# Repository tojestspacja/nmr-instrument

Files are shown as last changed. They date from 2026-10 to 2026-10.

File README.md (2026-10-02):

# Benchtop NMR instrument (TIGP 2026, Project 3)

Yi-Tsai Liang (`tojestspacja`). This repository is the canonical home of my Project 3: a 2 mT
benchtop NMR instrument built around the course's class board.

**Project site:** <https://tojestspacja.github.io/nmr-instrument/> ·
**Interactive simulator:** <https://tojestspacja.github.io/nmr-instrument/simulator/>

> **Status: design stage.** Designed and cross-checked in OpenSCAD; nothing printed, cut or measured
> yet. Every spectrum and signal here is simulated; there are no physical measurements so far.

## What lives where

| Content | Home |
| --- | --- |
| Project narrative, CAD, fabrication files, renders, simulator, analysis | **this repository** |
| The real PCBs, ESP32 firmware, NMR pulse sequence, the instrument's own web UI | [class-board-2026](https://github.com/TIGP-Experimental-Methods/class-board-2026), pinned in [`hardware/README.md`](hardware/README.md) |
| How the course finds this project | one card on the [class showcase](https://tigp-experimental-methods.github.io/showcase-2026/), linking to the site |

The rule: changing my Project 3 → work here. Changing the real PCB, firmware, pulse sequence or
instrument UI → work in class-board-2026. Changing how the course finds the project → edit only the
showcase card.

Three interfaces, three jobs:

```text
Course showcase card           "What is this project?"            -> links to the site
This site + /simulator/         "How is it built, how does it work?" -> simulation and explanation only
instrument-XXXX.local           "Operate the real instrument"        -> served by the ESP32 on local Wi-Fi
```

The simulator does not control the board, and cannot: it is a public HTTPS page, and the instrument
is a local-network device. Real scans start at `instrument-XXXX.local` → NMR → Apply settings → Start.

## Layout

| Path | What |
| --- | --- |
| `index.html` | the project site's landing page (GitHub Pages serves this repository's root, `main`) |
| `simulator/` | NMR Bench Setup: 3D bench and Bloch-equation pulse simulator (`simulator/README.md`) |
| `mechanical/` | the OpenSCAD project: housing, probe, B0 pair, bench checks, data model, simulator `spectrum.py` (`mechanical/README.md`) |
| `fabrication/` | laser and water-jet exports and `CUT-LIST.md`, generated by `mechanical/export_cut.py` |
| `hardware/README.md` | the class-board-2026 dependency: reference commit and the exact files |
| `tools/handin.py` | writes the course hand-in copy of the housing into class-board-2026 |

The CAD previews read the board meshes from class-board-2026 cloned beside this repository
(`../class-board-2026`); see `hardware/README.md`.

## History

The simulator started here; the OpenSCAD project started in class-board-2026
(`docs/students/yi-tsai/housing/`) and was brought in with `git subtree`, so its history is in this
repository too. That folder now holds only the course hand-in, generated by `tools/handin.py`.

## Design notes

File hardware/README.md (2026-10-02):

# Hardware and firmware

The instrument's electronics, firmware and on-board user interface are **not** in this repository.
They are developed in the shared course repository `class-board-2026`, which the instructor and other
students also change, and that repository is the source of truth for them. Nothing here copies them:
no firmware, no PCB project, no second version of the pulse sequence.

## Project 3 reference version

| | |
| --- | --- |
| Repository | [TIGP-Experimental-Methods/class-board-2026](https://github.com/TIGP-Experimental-Methods/class-board-2026) |
| Branch | `main` |
| Commit | [`eef00d20a10deca994a8efe07c588c22af2b9db0`](https://github.com/TIGP-Experimental-Methods/class-board-2026/tree/eef00d20a10deca994a8efe07c588c22af2b9db0) |
| Date | 2026-10-02 |

Everything in this repository was designed and checked against that commit: the housing against its
board meshes, and the simulator and documentation against its firmware. My working branch
`w1-yi-tsai` contains this commit and differs from it only under `docs/students/`.

| What | Path in class-board-2026 (links are pinned to the reference commit) |
| --- | --- |
| Main PCB | [`hardware/class-board.kicad_pro`](https://github.com/TIGP-Experimental-Methods/class-board-2026/blob/eef00d20a10deca994a8efe07c588c22af2b9db0/hardware/class-board.kicad_pro) |
| Front-panel PCB | [`hardware/front-panel/front-panel.kicad_pro`](https://github.com/TIGP-Experimental-Methods/class-board-2026/blob/eef00d20a10deca994a8efe07c588c22af2b9db0/hardware/front-panel/front-panel.kicad_pro) |
| Board meshes the housing is built round | [`hardware/release/`](https://github.com/TIGP-Experimental-Methods/class-board-2026/tree/eef00d20a10deca994a8efe07c588c22af2b9db0/hardware/release) (`class-board.stl`, `front-panel.stl`, `.step`) |
| NMR pulse sequencer | [`firmware/src/blocks/nmr/Sequencer.cpp`](https://github.com/TIGP-Experimental-Methods/class-board-2026/blob/eef00d20a10deca994a8efe07c588c22af2b9db0/firmware/src/blocks/nmr/Sequencer.cpp), one scan in [`runOneScan()`, lines 386–500](https://github.com/TIGP-Experimental-Methods/class-board-2026/blob/eef00d20a10deca994a8efe07c588c22af2b9db0/firmware/src/blocks/nmr/Sequencer.cpp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) |
| NMR firmware contract and default settings | [`firmware/NMR-FIRMWARE.md`](https://github.com/TIGP-Experimental-Methods/class-board-2026/blob/eef00d20a10deca994a8efe07c588c22af2b9db0/firmware/NMR-FIRMWARE.md) |
| Commands and record format | [`firmware/PROTOCOL.md`](https://github.com/TIGP-Experimental-Methods/class-board-2026/blob/eef00d20a10deca994a8efe07c588c22af2b9db0/firmware/PROTOCOL.md) |
| NMR instrument web UI (served by the ESP32) | [`host/pwa/panels/nmr.js`](https://github.com/TIGP-Experimental-Methods/class-board-2026/blob/eef00d20a10deca994a8efe07c588c22af2b9db0/host/pwa/panels/nmr.js) |
| Command-line client (`instrument nmr --csv`) | [`host/instrument.py`](https://github.com/TIGP-Experimental-Methods/class-board-2026/blob/eef00d20a10deca994a8efe07c588c22af2b9db0/host/instrument.py) |

## How a real scan runs

The pulse program runs on the ESP32. `runOneScan()` in `Sequencer.cpp` does this for each scan:

1. optional pre-polarization (`polarize_ms`, then `t_polarize_settle_ms`);
2. sets this scan's pulse phase;
3. blanks the receiver, then holds `TX_EN` high for the 90° pulse (`t90_us`); in echo mode it waits
   `tau_us` and gives the 180° pulse;
4. waits out the dead time (`t_dead_us`), while the coil is still ringing, then releases `RX_BLANK`;
5. starts the ADC burst at `t_acq_start_us` after the pulse and records for `t_acq_ms`.

The scan set repeats this `n_avg` times, `t_repeat_ms` apart, and cycles the pulse phase between
scans (CYCLOPS) when `cyclops` is on. The default values of these settings are in `NMR-FIRMWARE.md` at
the reference commit; they are deliberately not copied here, so they cannot go stale.

Note that class-board-2026's own guidance (`CLAUDE.md`, "Real-hardware code is unverified until
measured") treats the real-hardware branch of this code as a hypothesis until `hardware/docs/bring-up.md`
says otherwise; only its SIM mode has run.

## Three interfaces, three jobs

```text
Course showcase card ──────────► "What is this project?"   (one card, links here)

Public browser (GitHub Pages)
   └─► this site + /simulator/  ──► "How is it built, how does it work?"   simulation only

Phone or laptop on the local Wi-Fi
   └─► instrument-XXXX.local    ──► "Operate the real instrument"
          └─► ESP32 ─► TX / RX / ADC hardware
```

The public site cannot drive the board: it is served over HTTPS from the internet, and the
instrument is a plain `ws://` device on your local network. Real scans are started from
`instrument-XXXX.local` → **NMR** → **Apply settings** → **Start** (or **Pulse** for a single test
pulse), or from a laptop with `instrument nmr --n-avg 8 --csv fid.csv`.

## Building this repository's CAD against the boards

The OpenSCAD files in `../mechanical/` read the board meshes from a sibling checkout:

```text
tigp-2026/
├── class-board-2026/      (at the reference commit, or a later one)
└── nmr-instrument/        (this repository)
```

Only previews use them (`boards.scad`, the housing's assembly view, the simulator's mesh build);
none of the exported parts depends on them. If the boards change in `class-board-2026`, re-check the
housing against the new meshes and update the reference commit above.

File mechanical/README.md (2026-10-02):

# mechanical/: the OpenSCAD project

The housing, the probe, the B0 coil pair, the whole bench and the printable data model, as one
OpenSCAD project with one set of shared numbers. The story of how it was designed is on the project
site: <https://tojestspacja.github.io/nmr-instrument/>.

The files stay together in one folder because they include each other (`include <nmr-params.scad>`,
`use <housing.scad>`, `cut-*.scad` on the 3D files); splitting them would mean rewriting those links.
The flat-part exports go to `../fabrication/`.

| File | What it is |
| --- | --- |
| `nmr-params.scad` | the shared numbers: firmware defaults, the coil, water, copper. Change them here and nowhere else |
| `housing.scad` → `base-shell.stl`, `hood.stl`, `coupon.stl`, `bottom-plate.dxf`, `housing.png` | the printed housing; `part` = `shell`, `hood`, `coupon`, `plate` |
| `probe.scad` → `probe-former.stl`, `probe-sleeve.stl`, `probe-cradle.stl`, `probe.png`, `probe-b0.png` | coil former, 50 mL sample sleeve, tripod cradle; the B0 pair as a reference design |
| `instrument.scad` → `instrument.png` | the whole bench and its cross-checks: cables, RX tank, B0 drive and drift, steel near the sample, TX/RX |
| `boards.scad` | the two boards stacked, from the housing's own numbers |
| `spectrum.py` → `spectrum-data.scad` | the probe simulator (field over the sample, dead time, tank, coil heating), or real records from `instrument nmr --csv` |
| `spectrum.scad` → `spectrum.stl`, `spectrum.png` | the printable data model (simulated data) |
| `cut-common.scad`, `cut-housing.scad`, `cut-probe.scad`, `cut-spectrum.scad`, `export_cut.py` | every part flat for the laser and the water-jet; `py export_cut.py` writes `../fabrication/` |
| `img/` | renders for the project site |

## The board meshes

The housing is built round the boards' meshes, which belong to class-board-2026
(`hardware/release/`) and are not copied here. `housing.scad`'s `board_dir` reads them from a checkout
of class-board-2026 beside this repository; the reference commit is in `../hardware/README.md`. Only
previews need them; no exported part does.

## The course hand-in

The course collects the housing from class-board-2026 (`docs/students/yi-tsai/housing/`). That copy is
generated from this folder by `py ../tools/handin.py`; edit here, never there.

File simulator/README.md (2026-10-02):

# NMR bench simulator (Project 3: `simulator/`)

Part of the Project 3 site: <https://tojestspacja.github.io/nmr-instrument/simulator/>. **Simulation only:** it does not
control the instrument; the real pulse sequence is `runOneScan()` in class-board-2026
`firmware/src/blocks/nmr/Sequencer.cpp` (reference commit in `../hardware/README.md`).

A live 3D view of the whole setup — probe on its tripod inside the B0 Helmholtz pair, cabled to the
housing — with a pulse experiment that solves the Bloch equations for the real design. Open
`index.html` through a web server (it loads the meshes with `fetch`, which a `file://` page cannot):

```sh
py -m http.server 8000      # in this folder, then open http://localhost:8000/
```

## What the pulse experiment computes

- **Fields, exact (default):** precomputed in Mathematica by `build/nmr_exact.wls` and stored in
  `m/fieldmap-tube.json` / `m/fieldmap-bottle.json` (one entry per voxel on a 2.5 mm / 3 mm grid):
  Biot–Savart for the B0 pair with its real 28 × 27 mm winding cross-section (5 × 5 filaments per
  coil) and for every one of the class coil's 400 turns (222 in the first layer, 178 in the second),
  giving each voxel its line offset and the strength and direction of B1 perpendicular to the local B0.
  The page scales B0 with the current and adds the Earth's field along B0. **Approximate** (switch on
  the page, and the fallback if the maps do not load): 4th-order Helmholtz error and the on-axis
  finite-solenoid profile.
- **Pulse:** the class coil driven at 7.95 V pk (5.6 mA at 89.4 kHz); rotating component = half the
  linear field; an exact rotation per voxel about its effective field in the frame rotating at f_tx,
  off-resonance and the B1 direction included.
- **FID:** free precession at each voxel's own offset, intrinsic T2 = 2 s, T1 recovery 2.5 s.
- **Receiver:** reciprocity pickup with the same coil field (and phase), the Q = 10 tank tuned to
  88.47 kHz (C710 only + the coax, `instrument.scad`), mixing to the 5.4 kHz IF, 1.2 ms blanking,
  tank + OPA1656 noise 15.6 nV/√Hz over 15 kHz, ADC gain 1.02 V / 40 µV, 25 kS/s.

### Checked against SpinDynamica

`build/nmr_exact.wls` also runs the pulse on every voxel with SpinDynamica 3.7.1 (C. Bengs and
M. H. Levitt, *Magn. Reson. Chem.* 2017, doi:10.1002/mrc.4642) and computes the FID and spectrum
independently. Same voxels, f_tx 89.4 kHz, 417 µs, 1.5 A, no Earth field:

| | tube: `physics.js` | tube: SpinDynamica | bottle: `physics.js` | bottle: SpinDynamica |
|---|---|---|---|---|
| coil emf, µV pk | 0.902 | 0.902 | 1.643 | 1.643 |
| proton line, Hz | 89 559 | 89 560 | 89 559 | 89 560 |
| linewidth FWHM, Hz | 6 | 6 | 6 | 6 |
| T2* (envelope to 1/e), ms | 79.9 | 80.5 | 41.0 | 41.5 |
| 90° at the coil centre, µs | 417.4 | 417.4 | 417.4 | 417.4 |

What it shows about the design: at 1.5 A the pair gives **2.1035 mT**, not the thin-wire formula's
2.0997 mT, so the line sits at **89 560 Hz**, 160 Hz above the default f_tx (retune, or 1.497 A);
the 90° pulse at the coil centre is **417 µs** as the workbook says (the second layer is only 178
turns long, which the approximate model's even winding misses and puts at 451 µs); the 50 mL tube
gives **0.90 µV** at the coil, **8.8 µV** at the tank, a fifth of the 40 µV the receiver was sized
for (single-sample SNR about 4; the bottle 15.9 µV); T2* is **80 ms** in the tube, **42 ms** in the
bottle (it reaches the coil ends), line 6 Hz; the Earth's field along B0 moves the line 42.6 Hz per µT.

### Recomputing the field maps

Needs Mathematica (13.3 used) and SpinDynamica 3.7.x (free, <https://www.spindynamica.soton.ac.uk/downloads/>;
the newest release needs Mathematica 14.3). Point `SPINDYNAMICA` at its folder (the one holding
`SpinDynamica/`), then:

```sh
cd build
wolframscript -file nmr_exact.wls 2.5 Infinity tube      # about 5 min; writes exact-tube-*.json/.png
wolframscript -file nmr_exact.wls 3 Infinity bottle      # about 5 min
py compact.py tube ../m/fieldmap-tube.json
py compact.py bottle ../m/fieldmap-bottle.json
```

## Files

| File | What it is |
|---|---|
| `index.html` | the page (three.js r147 and pako from CDNs) |
| `physics.js` | the simulation, pure functions; `build/test-physics.js` runs it in Node |
| `m/*.txt` | the meshes: gzip(float32 positions + uint32 indices), base64 |
| `m/fieldmap-*.json` | the exact field maps, with the SpinDynamica results they were checked against |
| `build/nmr_exact.wls`, `build/compact.py` | the Mathematica / SpinDynamica computation and its packer |
| `build/exp-probe.scad`, `build/exp-housing.scad` | one component per run, in `instrument.scad`'s frame |
| `build/pack.py` | ASCII STL → the `m/*.txt` files |

## Rebuilding the meshes after a design change

```sh
cd build      # sources: ../../mechanical/*.scad; board meshes: ../../../class-board-2026/hardware/release/
# one STL per component (OpenSCAD on PATH); the list is in index.html, PARTS
openscad -o meshes/cradle.stl -D 'comp="cradle"' exp-probe.scad      # ... and so on
openscad -o meshes/box.stl    -D 'comp="box"'    exp-housing.scad
py pack.py                  # writes ../m/*.txt
node test-physics.js        # the physics numbers
```

The checks list in `index.html` quotes `instrument.scad`'s echoes; update it when they change.

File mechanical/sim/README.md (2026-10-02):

# NMR bench simulator

A live 3D view of the whole setup — probe on its tripod inside the B0 Helmholtz pair, cabled to the
housing — with a pulse experiment that solves the Bloch equations for the real design. Open
`index.html` through a web server (it loads the meshes with `fetch`, which a `file://` page cannot):

```sh
py -m http.server 8000      # in this folder, then open http://localhost:8000/
```

## What the pulse experiment computes

- **Field:** 3000 voxels of the sample in the B0 pair's field (Helmholtz, 4th-order error term) plus
  the Earth's field along B0.
- **Pulse:** the class coil driven at 7.95 V pk (5.6 mA at 89.4 kHz); B1 from the finite-solenoid
  on-axis profile, rotating component = half the linear field; an exact rotation per voxel about
  its effective field in the frame rotating at f_tx, off-resonance included.
- **FID:** free precession at each voxel's own offset, intrinsic T2 = 2 s, T1 recovery 2.5 s.
- **Receiver:** reciprocity pickup with the same coil profile, the Q = 10 tank tuned to 88.47 kHz
  (C710 only + the coax, `instrument.scad`), mixing to the 5.4 kHz IF, 1.2 ms blanking, tank +
  OPA1656 noise 15.6 nV/√Hz over 15 kHz, ADC gain 1.02 V / 40 µV, 25 kS/s.

What it shows about the design: the 90° pulse at the coil centre is **451 µs**, not the workbook's
417 µs (the coil is only 2.4 diameters long); the 50 mL tube gives **8 µV** at the tank, a fifth of
the 40 µV the receiver was sized for (single-sample SNR about 4); T2* is about **72 ms** (6 Hz line);
the Earth's field along B0 moves the line 42.6 Hz per µT.

## Files

| File | What it is |
|---|---|
| `index.html` | the page (three.js r147 and pako from CDNs) |
| `physics.js` | the simulation, pure functions; `build/test-physics.js` runs it in Node |
| `m/*.txt` | the meshes: gzip(float32 positions + uint32 indices), base64 |
| `build/exp-probe.scad`, `build/exp-housing.scad` | one component per run, in `instrument.scad`'s frame |
| `build/pack.py` | ASCII STL → the `m/*.txt` files |

## Rebuilding the meshes after a design change

```sh
cd build
# one STL per component (OpenSCAD on PATH); the list is in index.html, PARTS
openscad -o meshes/cradle.stl -D 'comp="cradle"' exp-probe.scad      # ... and so on
openscad -o meshes/box.stl    -D 'comp="box"'    exp-housing.scad
py pack.py                  # writes ../m/*.txt
node test-physics.js        # the physics numbers
```

The checks list in `index.html` quotes `instrument.scad`'s echoes; update it when they change.

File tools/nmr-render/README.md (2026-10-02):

# nmr-render — local visual oracle for the NMR bench scene

A tiny native renderer that turns the 3-D NMR bench into a PNG from the command line, so camera framing,
sample-holder visibility, B0/B1 readability, transparency and the exploded view can be **inspected**, not guessed
from source. It is a development/verification tool — **not** a replacement for the public Three.js site.

```
         canonical geometry  (legacy/simulator/m/*.txt, from the OpenSCAD via build/pack.py)
                /        \
               v          v
   Three.js/WebGL      nmr-render (this tool)
   public site              |
                            v
                           PNG
```

## Why it exists

Visual work on the scene was being judged from source code alone, which is unreliable. This tool makes the loop:
*edit presentation → render → inspect the PNG → revise.*

## Why a CPU rasteriser (not GLFW/OpenGL)

The primary user runs in a headless automation sandbox where a GPU OpenGL context is unreliable. A small software
rasteriser is deterministic and depends only on `stb_image_write.h` (vendored), so it always runs here. It is the
"smallest reliable native pipeline." A GLFW/OpenGL backend could be added later for GPU rendering, behind the same CLI.

## Geometry source (no duplication)

Geometry is **not** defined in this tool. `transcode.mjs` re-containers the canonical packed meshes
`legacy/simulator/m/*.txt` — the exact meshes the Three.js site loads, themselves generated from the OpenSCAD in
`legacy/mechanical/` + `legacy/simulator/build/*.scad` by `pack.py` — into one `assets/scene.bin`. Only
**presentation** (per-part colours, per-preset visibility/opacity, cameras) lives in `src/main.cpp`.

Canonical coordinate frame (unchanged, verified): **+x** = sample / RF-solenoid axis, **+y** = Helmholtz / B0 axis,
**+z** = up.

## Build & render

```sh
node transcode.mjs                       # legacy/simulator/m/*.txt -> assets/scene.bin  (needs Node)
cmake -S . -B build -G Ninja
cmake --build build
./build/nmr-render.exe --preset instrument --scene assets/scene.bin --output artifacts/instrument.png
```

## Presets

| Preset | Question it answers | Shows |
|---|---|---|
| `instrument` | "What is this instrument?" | probe centred, Helmholtz pair around it, holder legible, PCB/wiring hidden, narrow-FOV (low distortion) |
| `physics` | "How does the NMR geometry work?" | **y-up**: B0 (blue) vertical, B1/coil axis (orange) horizontal, pair as two coils — B0 ⟂ B1 obvious |
| `probe` | "What holds the sample?" | close-up of tube, sleeve, former, winding, cradle, tripod |
| `exploded` | "How is it assembled?" | probe stack separated along real axes, cabling to the PCB |

## CLI

`--preset <name>` · `--output <path>` · `--scene <scene.bin>` · `--projection ortho|perspective` ·
`--azimuth <deg>` · `--elevation <deg>` · `--distance <mm>` · `--fov <deg>` · `--width/--height` ·
`--show-fields/--no-fields` · `--show-wiring/--no-wiring` · `--show-pcb/--no-pcb` · `--show-grid/--no-grid` ·
`--no-holder`. Exit code is nonzero on failure.

## Generated vs tracked

Generated (git-ignored): `build/`, `assets/scene.bin`, `artifacts/*.png`.
Tracked: source, `transcode.mjs`, `CMakeLists.txt`, vendored `third_party/stb_image_write.h`, and the reference
renders in `artifacts/render-reference/`.

## Relationship to the WebGL site

Use this tool to iterate camera/visibility fast. Once a composition is chosen, apply the corresponding choices to the
public Three.js page (`legacy/simulator/index.html`) and do a final browser check when browser rendering is available.
A good OpenGL/CPU render does **not** prove CSS layout, WebGL transparency or responsive behaviour are correct.

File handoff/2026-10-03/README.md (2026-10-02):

# Account-Switch Handoff Package

## Purpose

Continue the benchtop NMR rewrite after an account/session interruption without restarting work, losing uncommitted files, or inheriting unsupported claims. All handoff documentation is in English.

This package preserves project intent, prior agent reports, recorded implementation progress, the interruption point, and a safe recovery procedure. It does not transfer credentials, hidden model state, running agents, or processes.

## Critical source discrepancy

**The supplied `nmr-instrument.zip` is not the `v2` working tree described in the attached session transcript.**

The ZIP contains `main` at `0914edbc5f9424503e6046394dd632a815474fc3`, the public-site/simulator/OpenSCAD layout, and no `v2` reference. The transcript records later canonical configuration, a C++ core, pulse programming, Python/WASM integration, tests, and partial ESP-IDF firmware.

This does not prove that the user's live Windows folder lost any work. The actual folder may still contain `v2`, including valuable uncommitted firmware. Inspect and protect that folder first.

## Installation on the original computer

1. Pause other agents writing to the same working tree. Do not assume logging out stopped child processes.
2. Preserve an access-controlled backup/checkpoint of the live source, including required untracked work and local-only evidence. Review ignored files and secrets separately.
3. Extract this package into a staging folder.
4. Copy **only** `RESUME_AFTER_ACCOUNT_SWITCH.md` and `handoff/2026-10-03/` into the live `nmr-instrument` root. Compare rather than blindly overwrite any existing destination.
5. Do **not** extract the old source ZIP over the live project or replace its `.git` directory.
6. Open the live project with the new session and paste `RESUME_PROMPT.md`.

Expected placement, based on the historical local path:

```text
C:/Users/Liang/tigp-2026/nmr-instrument/
├── RESUME_AFTER_ACCOUNT_SWITCH.md
├── handoff/2026-10-03/
│   ├── CURRENT_STATE.md
│   ├── RECOVERY_PLAN.md
│   ├── NEXT_ACTIONS.md
│   ├── ...
│   └── capture_state.py
└── <all existing project files, unchanged>
```

That Windows path is a locator from the transcript, not a live directory inspected during package preparation.

## Read order

Start with the repository-root entry file, then `CURRENT_STATE.md`, `RECOVERY_PLAN.md`, `NEXT_ACTIONS.md` and `OPEN_ISSUES.md`. Consult `DECISION_LOG.md` and `TEST_EVIDENCE.md` before changing architecture or interpreting a historical test claim. `TRANSCRIPT_INDEX.md` locates targeted source evidence.

The previously drafted `PROJECT_CONTRACT.md`, `AGENT_PLAN.md` and traceability documents remain useful intent if installed in the live tree. Do not assume they exist merely because they appeared in chat, and do not let an old example silently revert a later implemented change.

## Optional read-only diagnostic

From the live project root:

```powershell
py handoff/2026-10-03/capture_state.py --root .
```

The script prints JSON. It does not modify source, Git refs/index/config, credentials or the checkout; it does not access the network, install dependencies, build, flash or operate the instrument. Exit code `3` means expected v2 continuation files are not sufficiently present, not that an NMR test failed.

## Limits

Missing v2 source has **not** been silently recreated or installed. The evidence directory is historical text, not a verified source backup. The user's current Windows processes, local branches, remote state and board connection must be checked by the receiving agent.

No original implementation file was changed. Creating a handoff does not promote any NMR validation state.

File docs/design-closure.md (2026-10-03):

# Design closure — from a plausible model to a buildable low-field NMR instrument

Engineering-closure working document. Phases 1–2 (audit + physics closure) are **done and quantified below**; Phases
3–10 are staged with what can be done in CAD/analysis vs what needs physical hardware. Numbers come from the shared
field solver (`physics/`, via the WASM core over the real voxelised sample), not assumptions. Frame: **+x** sample /
RF-solenoid axis, **+y** Helmholtz / B0 axis, **+z** up.

Source-of-truth discipline (§21): the real PCB + firmware stay authoritative in **class-board-2026** (pin a commit for a
physical build); mechanical/instrument/docs work lives here in **nmr-instrument**. No firmware/PCB is duplicated.

---

## Phase 1 — Current-state audit (gap list)

| Item | State | Gap |
|---|---|---|
| RF former, sample sleeve, cradle | CAD + STL (`legacy/mechanical/probe.scad`) | sleeve/cap is the axial stop but the **datum chain to the B0 centre is not explicit** |
| Helmholtz ring formers + spacing rails/brace | CAD (`probe.scad` b0_ring ref; `cut-probe.scad` B0 rails) | **no coaxiality/alignment datum**, no mount to a common base |
| Housing for the boards | CAD (`housing.scad`, `cut-housing.scad`) | a **separate enclosure**, not integrated with probe + magnet |
| B0 windings, PCB models, cables | **presentation only** (sim meshes) | not fabrication geometry; cables are decorative |
| Base / frame tying magnet + probe + electronics | **absent** | the three subsystems have no common mechanical reference |
| Electronics tray / standoffs integrated with the instrument | **absent** | boards sit in their own housing beside the experiment |
| Cable routing / strain relief as real features | minimal (probe stub tie, anchor) | no routed paths/clips between subsystems |
| Active NMR volume (ROI) definition | **absent** | now defined below |
| Shim hardware | none (Level 0) | decision pending measurement |

## Phase 2 — Physics closure (computed over the real 50 mL tube, I = 1.5 A, γ̄ = 42.576 MHz/T, 2 mm grid, 7924 voxels)

**B0 over the sample:** f_mean **89 528 Hz**; peak-to-peak **304 Hz (3400 ppm)**; RMS 58 Hz. Receive-weighted
(b1⊥²·V) RMS **35 Hz (388 ppm)**. The simulator's "6 Hz FWHM" is the cusp of a line with a long tail — the bulk of the
signal is spread over tens of Hz.

**B0 along the coil axis x (transverse to B0):** flat to within +17…+31 Hz for |x| ≲ 30 mm, then falls hard toward the
ends: −24 Hz at ±40 mm, **−116 Hz at −50 mm, −204 Hz at −60 mm**. The long sample's ends sit where the Helmholtz field
has dropped — they contribute broad, off-resonance signal.

**The central result — active length vs linewidth (receive-weighted):**

| Active length (x) | rel. received signal | f RMS | p2p | signal within ±5 Hz |
|---|---|---|---|---|
| **100 mm (current)** | 98 % | **23.9 Hz** | 172 Hz | **11 %** |
| 80 mm | 91 % | 11.3 Hz | 77 Hz | 57 % |
| **60 mm** | **78 %** | **4.4 Hz** | 33 Hz | **82 %** |
| 40 mm | 55 % | 1.6 Hz | 13 Hz | 99 % |
| 30 mm | 42 % | 0.9 Hz | 8 Hz | 100 % |

### Finding (§3, §4): the 100 mm RF coil / 50 mL sample is too long for the B0-homogeneous volume

The active sample volume extends well beyond the homogeneous region, so ~90 % of the received signal lies outside ±5 Hz
of the line. Restricting the **active region to ~60 mm** keeps **78 % of the signal** while cutting the field RMS **≈5×**
(24 → 4.4 Hz) — a large linewidth/T2* win for a modest signal loss. 40 mm gives a near-ideal line (1.6 Hz) at ~55 %
signal. The **active NMR ROI** is therefore the central cylinder **|x| ≲ 30 mm** (not the full 100 mm), intersected with
the RF-sensitive and B0-homogeneous volumes.

### V1 vs V2 decision (§2, §8): keep V1; do not rotate to vertical

The horizontal simple solenoid is physically correct (B1 ≈ +x ⟂ B0 = +y), has an excellent filling factor and B1/I, and
the measured deficiency is **length**, not orientation. The fix is a **V1 refinement — shorten the active region to
~60 mm** (shorter winding, or a defined ROI with the sample centred), *not* a vertical top-loading V2. Rotating the
sample ∥ B0 would force B1 ∥ B0 (invalid) and require a transverse (saddle/cos-θ) coil — a separate study only, **not
justified by this data**. V1 stays the baseline.

### Phase 3 implemented — 60 mm coil adopted (2026-10-03)

Done as a coupled change through the single source of truth, verified green:
- `design/instrument.yaml`: `rf_coil` → length 0.060 m, 266 turns (2×133), B1/I **4.611195e-3 T/A** (Biot–Savart solver),
  L ≈ 1.87 mH, R ≈ 4.46 Ω (estimates, to be measured); `gen_config` recomputed the chain and **t90 → 369 µs**,
  coil current 6.9 mA, and passed all consistency checks. Config sha updated.
- **Validation frozen at 100 mm:** added `legacy_probe()` + ABI `nmr_legacy_fields_at`; `test_field` and `test_golden`
  now cross-check the solver against the Mathematica golden maps at the *frozen 100 mm* reference, independent of the
  design coil. So the solver stays independently validated; the 60 mm field is computed by that validated solver.
- Mechanical: `probe.scad` → 60 mm/266-turn winding (former 85 mm; the 50 mL tube overhangs 16 mm, datum = cap at the
  sleeve flange; the sample covers the winding z 6–66 mm). Fabrication STLs + sim meshes regenerated; probe render
  inspected (`tools/nmr-render` probe preset).
- Tests: `ctest` 7/7, `pytest` 16/16 (golden on frozen 100 mm; parity on 60 mm config), OpenSCAD renders manifold.
- Still to recalibrate on the bench (§16): t90 by nutation, and L/R/Q with the real matching network — the config
  values are the best estimates, flagged accordingly.

### Shim decision (§5): defer to measurement; expect Level 0–1

At a 60 mm active region the Helmholtz pair alone gives ~4 Hz RMS, comparable to the intrinsic ~2 Hz water line. That is
likely enough for a first FID/spectrum. Start **Level 0** (geometry + reproducible positioning); add a **Level 1** linear
shim only if the *mapped* field / *measured* linewidth demand it. Do not add higher-order shims pre-emptively.

---

## Phases 3–10 — staged plan

### Phase 4 implemented — magnet structural closure + baseplate (2026-10-03)

The B0 pair already had laser-cut rails + braces (`cut-probe.scad`) that seat both ring stacks at the 200 mm spacing,
but they were never in the 3-D assembly and there was no common base. Added (faithful solids from the same rail/ring
numbers, in `cut-probe.scad`): `b0_rail3d`/`b0_brace3d` (the two rails at x = ±100 seating the rings, tied by braces)
and a `baseplate()` that carries both rails **and** the probe tripod — one mechanical reference (x coil axis, y B0,
z up). Exposed as render components (`exp-probe.scad` → sim meshes) and on the website (new "Frame" group); the renderer
`instrument`/`exploded` presets show the supported instrument on its base, verified by inspection. Clearance echo
confirms the baseplate spans both rails + the probe. Still open for Phase 6: a full `instrument()` interference pass and
the electronics tray's mount to this baseplate (Phase 5).

### Phase 5 — electronics integration (2026-10-03): mostly already done

Finding: `housing.scad` was **already a complete electronics assembly** with real board dimensions — outline 180×115 mm
(the KiCad frame), real M3 mount holes `[[4,19],[176,19],[4,111],[176,111]]`, cover standoffs, a laser-cut bottom plate
on nut-pocket bosses, connector cut-outs (16 SMA, OLED hood, screw terminals with cover windows + front notches, rear
openings) and service access (removable plate). It has a defined position in `instrument.scad` (`housing_gap` = 450 mm
from the sample, deliberately far for RF/magnet isolation). So §10's requirements were met and the "naked/floating PCB"
concern does not apply. The two genuine gaps (§11, §12D) are now added and verified (direct OpenSCAD render + z-check):
- **bench feet** (`housing_feet`): four feet under the bottom plate (z −40.7 → −45.7, i.e. 5 mm proud of the plate);
- **cable strain relief** (`strain_relief`): a clamp bar outside the front/terminal wall with zip-tie slots, so a tug on
  the TX pair reaches the bar, not J32 / the OPA564 output.

The electronics stay a separate unit on the bench (not rigidly joined to the magnet baseplate — the 450 mm gap is
intentional); the common reference is the documented layout in `instrument.scad`.

### Phase 6 — full instrument assembly + interference/serviceability pass (2026-10-03): clean

The whole bench is now one assembly (baseplate → magnet rails/braces cradling both rings → probe on its tripod at the
magnetic centre → cables → electronics), rendered via the `tools/nmr-render` **`assembly`** preset and inspected. The
interference/serviceability screen (AABB over the assembled scene + model self-checks + `instrument.scad` echoes) is
clean:
- probe radial envelope 17–23 mm sits well inside the ring aperture (171 mm) — **no collision**;
- rings clear the baseplate by 10 mm; the tripod is seated on the plate; cables stay above the plate (no tunnelling);
- electronics 236 mm clear of the magnet (and nearest steel 492 mm ≥ 300 mm; rings clear the housing front, 217 vs 450);
- **serviceability:** the sample inserts/removes along x **through the ring aperture** (rings at y = ±100, nothing on
  the x axis) without disassembling the magnet; the probe lifts out +z through the same aperture; the housing bottom
  plate is removable.

A clearance self-check echo in `cut-probe.scad` re-verifies this on any geometry change. Reference render:
`tools/nmr-render/artifacts/render-reference/assembly.png`.

**Doable now in CAD/analysis (with the `tools/nmr-render` oracle for visual checks):**

- **Phase 3 — Probe mechanical closure.** Make sample positioning a real datum chain: sleeve flange + tube cap as the
  axial hard stop referenced to the winding centre (x = 0), radial centring in the bore, and a defined ROI label. If we
  adopt the 60 mm active region, add a shorter-winding variant parameter (`wind_l`) and re-verify B1/I, L, Q, t90.
- **Phase 4 — Magnet structural closure.** Coaxiality + spacing datums for the Helmholtz pair (rails already fix
  spacing; add alignment features) and a mount to a common base.
- **Phase 5 — Electronics integration.** Real board dimensions (from `class-board-2026/hardware`), a tray + standoffs,
  connector access, strain relief.
- **Phase 6 — Full-instrument assembly.** One OpenSCAD `instrument()` of assemblies (base / helmholtz / probe /
  electronics / cable) with interference + serviceability checks, rendered and inspected.
- **Phase 7 — Fabrication outputs + BOM + assembly order.** Regenerate STL/DXF from the closed design.

**Requires physical hardware / measurement (procedures authored here; cannot be executed in this environment):**

- **Phase 8 — RF/electrical validation:** measure L/R, tune/match near the Larmor line, verify TX current, **recalibrate
  t90** (the 417–458 µs value is invalid after any coil change), measure ring-down/recovery.
- **Phase 9 — Commissioning:** energise B0, measure/ map the field around the ROI, compare to this simulation, acquire
  the first FID, check I/Q polarity, average, measure linewidth/T2*.
- **Phase 10 — Shim decision:** from the measured map/linewidth, add only justified shim DOF.

### Commissioning sequence (§18) — mechanical → B0 → RF → NMR → shim
Assemble frame → mount + align Helmholtz (verify R, spacing, coaxial) → mount cradle, insert probe, confirm ROI at
centre → mount electronics, route cables → measure coil R, energise B0 safely, measure central B0, **map B0 over the
ROI and compare to this doc** → measure RF L/R, tune/match, verify TX, calibrate t90, measure ring-down → first FID,
check I/Q, set gain, average, measure linewidth → shim only if the data demand it, then re-verify sample-insertion
repeatability.

### Acceptance criteria (§19)
- *Mechanical:* Helmholtz spacing/alignment repeatable; probe constrained; sample inserts/removes without disturbing
  alignment and returns to the ROI; PCB mounted; cables strain-relieved.
- *Electrical:* B0 coils at current without excess heating; RF tunes near Larmor; TX reaches amplitude; receiver
  recovers; ADC acquires.
- *Magnetic:* measured B0 ≈ predicted; ROI homogeneity quantified; map vs simulation.
- *NMR:* a real sample gives a reproducible FID, coherent phase, averaging gain, a spectrum consistent with the measured
  B0, and a **measured** linewidth. Keep "simulated" and "measured" spectra clearly distinct throughout.

## Remaining uncertainties needing physical measurement (§23, §27)
Actual B0 vs predicted; mapped ROI homogeneity vs the table above; B1/I (→ t90) after any coil change; coil L/Q with the
real matching network + coax; TX/RX isolation and receiver recovery on one shared coil (the open blocker — see the
simulator's "TX and RX on one coil" check); sample-insertion repeatability; whether the 60 mm active region is adopted.

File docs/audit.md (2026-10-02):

# Milestone 0 — audit of the legacy sources

Sources audited (read-only):

| Archive | Repository | Commit |
|---|---|---|
| `class-board-2026 (2).zip` | TIGP-Experimental-Methods/class-board-2026, branch `w1-yi-tsai` | `da56d2b` (hardware/firmware identical to `main` @ `eef00d2`) |
| `nmr-instrument.zip` | tojestspacja/nmr-instrument, `main` | `0914edb` (now under `legacy/` on this branch) |

The audit ran KiCad 10 ERC/DRC, exported the netlist, built both firmware environments with PlatformIO, re-ran the Biot–Savart
field-map computation in Mathematica 13.3 and checked the Bloch code against an RK4 integration. Nothing in the legacy
sources has ever run on real hardware. Raw audit outputs: `validation/legacy-audit/`.

## 1. Feature inventory

### Electronics (class-board-2026, KiCad authority)

| Feature | Class | Evidence / reason |
|---|---|---|
| Si5351A (25 MHz crystal): CLK0 50 MHz DDS clock, CLK1 = 4·f_LO into a 74HC74 Johnson counter (I/Q LO) | RETAIN | Sound; one reference for TX and LO |
| AD9834 DDS + 3 MHz 3rd-order reconstruction filter | RETAIN | Values consistent (R801 6.8 k, 0.636 Vpp) |
| AD9834 RESET/SLEEP pins only pulled down, never driven | REIMPLEMENT | Reset only via control word; no hardware phase reset |
| OPA564 power stage, G = 25 (R807/R808), I_LIM 1.5 A (R809 11 k) | RETAIN topology | — |
| OPA564 I_FLAG/T_FLAG unconnected (DNP pull-ups, `pins.h:96-97` = −1) | REIMPLEMENT | Over-current abort documented but impossible |
| TX output snubber R814 10 Ω + C817 10 nF to GND | VERIFY | Loads a shared coil's tank heavily during receive (179 Ω at 89 kHz) |
| Crossed diodes D703/D704 directly on the RX node; **no T/R switch** | REIMPLEMENT | With one coil on TX and RX the diodes carry ≈1.4 A from the OPA564 (at I_LIM) and B1 drops ~6× — `docs/tx-rx.md` |
| Tank C710+C711+C712 all fitted = 1.322 nF on the board's RX node | VERIFY | Resonance ≈87 kHz, not 89.4 kHz; a tank on the board side of the cable is cable-dependent |
| OPA1656 LNA stage 1, gain set via header J3 | REIMPLEMENT | **Without a J3 shunt stage 1 has no feedback** (netlist: J3-1 and J3-2 on different nets) |
| DG419 blanking between LNA stages (RX_BLANK, GPIO8) | RETAIN | Correct place for post-LNA blanking; does not isolate the coil |
| Double-balanced TS5A23157 commutating mixer + OPA1612 difference amplifiers | RETAIN / VERIFY | IF gain computes to ≈10, documented 20; unequal P/N poles |
| ADS8688 on shared SPI2 (with AD9834 and DAC8563), ±5.12 V range, channels AIN3 (I) / AIN2 (Q) | VERIFY | Sustained two-channel rate on a shared bus not demonstrated |
| DRV8871 H-bridge as B0 driver, I_TRIP 2.0 A (R920 32 k), **no current sense** | REIMPLEMENT | Chopping limiter, not a regulated current source; B0 drifts with coil temperature; chopping ripple modulates B0 |
| Polarizer FET AOD4184A + UCC27517 | RETAIN / VERIFY | Driver VDD only via J12 shunt; ISENSE_COIL not routed to the ADC |
| One GND net on both boards (Decision #73) | VERIFY | 1000× receiver shares copper with the polarizer (13 A), H-bridge and TX returns |
| +VEXT TVS SMBJ26A (clamps ~42 V) | REIMPLEMENT | Above the OPA564's 26 V absolute maximum |
| ERC/DRC | RETAIN | ERC 0 errors (2 cosmetic warnings), DRC 0 violations, 0 unconnected |

### Firmware (class-board-2026 `firmware/`, Arduino-ESP32 2.0.17)

| Feature | Class | Evidence / reason |
|---|---|---|
| TX gate = `digitalWrite` + `esp_timer` busy-wait (`Sequencer.cpp:427-430`) | REIMPLEMENT | Pre-emptible (AsyncTCP prio 10, arduino_events on core 1): an over-pulse lasts as long as the pre-emption; no flag to catch it |
| ADC burst: Arduino `SPI.transfer32`, `esp_timer` polling per sample (`Ads8688.cpp:163-225`) | REIMPLEMENT | Jitter; late samples taken back-to-back silently; header reports requested, not achieved, rate |
| NMR-FIRMWARE.md ↔ code (ADS8688 "spi_device_polling_transmit", "critical region", "priority high", AD9834 PHASE1 90/180) | REMOVE | 10 documented discrepancies (firmware audit §2) |
| **Phase coherence: TX (PLLA/DDS) and LO (PLLB) free-run; scan start is ESP32-timed** | REIMPLEMENT (missing) | IF phase at the pulse is random per scan → averaging and CYCLOPS incoherent on hardware; SIM hides it (`Sequencer.cpp:627-629`) |
| Grow-only PSRAM buffers at `config` | RETAIN | No per-scan allocation |
| `Dsp.cpp` pure functions (offset, boxcar decimation, CYCLOPS rotation, radix-2 FFT, parabolic peak) | RETAIN concept, REIMPLEMENT | Correct but untested; no digital mixing; three incompatible spectrum implementations (firmware, JS, Python; 2√2 scale differences) |
| Si5351/AD9834 drivers | RETAIN / VERIFY | AN619-correct; `setClk1` return unchecked; SPI mutex inside the timed path |
| Per-scan 400 kB WebSocket broadcast under a lock | REIMPLEMENT | Heavy; jitters TR |
| `instrument.py next_binary` returns the oldest parked record | REMOVE | Returns scan 1, not the average |
| Full-record Hann window (`instrument.py:287-302`) | REMOVE | ≈10 dB SNR loss for a T2* ≪ record |
| Four simulators (firmware SIM, ADS8688 SIM, dev-nmr.html, docs) | REMOVE | Replace with the shared physics core |
| CI: build only, ruff; **no unit tests** | REIMPLEMENT | — |

### Physics and simulation (nmr-instrument `legacy/`)

| Feature | Class | Evidence / reason |
|---|---|---|
| Rodrigues rotation about −B_eff in the f_tx frame; precession e^{−iΔωt} (`physics.js`) | RETAIN | Matches RK4 of dM/dt = γ M×B to 5 decimals |
| Curie M0, reciprocity pickup, rotating B1 = ½ linear field | RETAIN | Analytically correct |
| Exact Biot–Savart field maps (`fieldmap-*.json`), elliptic-integral loop kernel | RETAIN as golden data; port the kernel | Recomputed voxels match every printed digit |
| Approximate 4th-order Helmholtz + on-axis solenoid | REIMPLEMENT | B0 ignores N rounding (311.4→312); B1 has no radial/two-layer model → t90 451 µs vs exact 417.4 µs |
| `nmr_exact.wls` SpinDynamica comparison | REIMPLEMENT | Handedness mismatch (pulse about +H, FID e^{−iΩt}); explains the 0.6 ms "agreement" gap |
| Reported "FWHM 6 Hz" | REMOVE | Window-limited by the 0.2 s record (1.207/T) |
| Scalar tank gain, no transient, unshaped noise | REIMPLEMENT | Needs complex response |
| `spectrum.py` sample model (r 15 mm, x −50…25 mm) | REIMPLEMENT | Disagrees with the other models (r 14 mm, −58…+25 mm + cone) |
| Coil-heating drift model | RETAIN | Self-consistent |
| `test-physics.js` | REIMPLEMENT | Prints, asserts nothing |
| Line at 1.5 A: 89 400 / 89 560 / 89 585 Hz in three models | REIMPLEMENT | One field model, one source of geometry |

### Mechanical and site

| Feature | Class | Reason |
|---|---|---|
| OpenSCAD housing, probe, B0 pair, cut files | RETAIN as reference; REIMPLEMENT canonical in build123d | Not STEP/BREP; board geometry imported as connector-only STL |
| Mesh assets for the 3D bench | RETAIN (assets) | — |
| Housing hand-in snapshot (class-board) | RETAIN | Course requirement |

## 2. Known problems that block real NMR (ordered)

1. **Phase coherence between TX, LO and acquisition** — averaging cannot work (ADR-0006).
2. **No T/R switch on a shared coil** — the transmitter is shorted into the RX clamp diodes (ADR-0007).
3. **B0 is not current-regulated and not measured** — 23 W heating moves the line ≈138 Hz/min; DRV8871 chopping modulates B0 (ADR-0008).
4. **LNA stage 1 open-loop without the J3 shunt** — bring-up step, then a schematic fix.
5. **Software-timed TX gate** — over-pulse risk with no hardware flag (ADR-0005).
6. Tank as fitted ≈87 kHz; IF gain ≈half the documented value; OPA564 flags unwired; TVS above the OPA564's absolute maximum.

## 3. Dependency map (legacy)

```text
nmr-params.scad ──regex──► spectrum.py           (constants copied by hand into:)
                          physics.js P{}         Sequencer.h defaults, nmr.js defaults,
                          nmr_exact.wls          instrument.py NMR_DEFAULTS, dev-nmr.html,
                                                 NMR-FIRMWARE.md, PROTOCOL.md
KiCad (class-board) ──export──► release/*.stl/.step ──► OpenSCAD housing, simulator meshes
firmware Sequencer ──WebSocket──► PWA nmr.js (own FFT) / instrument.py (own FFT)
```

Every arrow labelled "by hand" is replaced in v2 by generation from `design/instrument.yaml`.

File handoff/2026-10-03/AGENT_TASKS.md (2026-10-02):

# Resumed Agent Assignments

## First wave: recovery owner

Use one agent to establish the actual live tree, backups/WIP, source availability, baseline identity and write ownership. Do not start implementation workers against a possibly stale checkout.

Output: a live checkpoint based on `CHECKPOINT_TEMPLATE.md`, identifying recovery case and the exact next task.

## Subsequent roles — up to three focused agents

| Role | Scope | Allowed ownership | Deliverable |
|---|---|---|---|
| Integration builder | Finish existing M4 main/control integration and build failures | `firmware/main/`, build registration and specifically assigned integration files | Changes, full build logs, error/safe-state tests and remaining gaps |
| ADC/phase reviewer | Independently challenge I2S/ADS8688 framing, aperture timing, skew, capture and faults | Assigned tests/review files or an isolated worktree; no concurrent builder-file edits | Counterexamples, protocol questions, synthetic tests and bench acceptance criteria |
| Continuity/verification owner | Preserve evidence; check native/WASM/config parity and traceability; independently test integration | Handoff/evidence and agreed verification scripts | PASS/FAIL/NOT_RUN/SKIPPED tied to actual source; no self-certified hardware result |

If only one agent is available, do the roles sequentially and acknowledge that verification is not independently authored. Do not invent agents or expect old task IDs to survive.

## Cross-domain questions

Require precise answers for conversion-to-channel mapping, I/Q aperture times, first-sample timestamps, captured phase meaning, missing ECO-input detection, overrun reporting, and whether simulator/firmware correct skew exactly once.

Ask the hardware reviewer to separate actual board connectivity from proposed changes. A current-source design, T/R topology or capture-pin proposal is not applied hardware until evidence says so.

## Ownership and durable handbacks

Each task has a task ID, baseline HEAD/config hash, allowed paths, dependencies, output and acceptance test. Do not let two agents edit the same files or both rewrite shared status. A coordinator checks which revision each report examined before integration.

Every handback must be saved:

```text
Task and scope:
Baseline/final source identity:
Files inspected:
Files changed:
Verified result and raw log:
Failed / skipped / not run:
Unresolved question:
Next exact action:
```

Preserve relevant temporary outputs in stable project evidence paths. Do not include credentials or unrelated personal material.

## Avoid repeated directory audits

The three original reports are already preserved in `evidence/legacy-*-audit.md`. Reuse their historical findings; rerun targeted checks only for changed inputs, missing evidence or contradictions. The immediate goal is recovery and completion of the interrupted integration.

## Background tasks

Use only actual supported execution facilities. Record command, directory, output and observed process state. Do not assume an account switch resumes a child process or makes an old task ID valid. Do not assign a reasoning agent simply to wait for a build.

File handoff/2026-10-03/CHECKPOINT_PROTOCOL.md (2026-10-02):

# Checkpoint Protocol

## Proposed operating rule

Keep stable mission, changing task state, decisions, issues, source history and test evidence in durable files. A new agent should reconstruct engineering progress without the old account's chat memory. This is a project procedure, not a claim that a provider automatically loads particular filenames.

## Before switching

Finish a small coherent unit or clearly record the stopping point. Pause conflicting writers. Preserve staged, unstaged and untracked source plus important local-only evidence. Review ignored artifacts and secrets separately; do not copy the whole home directory or account configuration.

Update one checkpoint with actual source/config identities and raw logs. Separate completed code, tests executed, missing tests and incomplete outputs. A plan listing requirements is not a record of current implementation state.

Check that the bootstrap file points to the current checkpoint and a finite next task.

## After switching

Read the checkpoint, inspect the live tree, compare identities, resolve mismatches and run targeted smoke tests. Do not clean or regenerate the tree before recording what is there. Distinguish inherited results from checks actually rerun, then continue safe implementation.

## When to checkpoint

After meaningful milestones, interface/design changes, important failed validations, major file moves, and before logout/context reset. If the old session is already blocked, reconstruct from saved files and logs with explicit uncertainty.

## Concurrency

One coordinator owns shared checkpoint/issue state. Other agents use disjoint files or isolated worktrees and include baseline identities in their handbacks.

## Permissions

Use only material authorized for the receiving account. Do not export organization credentials, tokens, session authentication files or unrelated private data. Local-file access does not itself authorize remote pushes or hardware operation.

## Completion standard

The next agent must be able to identify actual source state, WIP, last real test, unresolved physical risks and the next finite action. Do not promise restoration of hidden model state or omitted work.

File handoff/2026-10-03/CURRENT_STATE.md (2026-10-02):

# Current State — Available Snapshot and Intended Continuation

Prepared: 2026-10-03. This is an initial handoff reconstructed from supplied materials, not a live update from the user's Windows computer.

## Executive state

**Available ZIP:** legacy/main snapshot. **Intended continuation from the later transcript:** Milestone 4, partial ESP-IDF firmware after native-core/pulse-programming and WASM checkpoints. **Immediate action:** locate and protect the actual live v2 working tree before editing.

The earlier generic handoff example that stopped at Milestone 1 is outdated relative to the attached execution record. This does not turn transcript-only work into source present in the ZIP.

## Evidence vocabulary

| Label | Meaning |
|---|---|
| `ARCHIVE_OBSERVED` | Directly inspected in the supplied archive or its Git metadata. |
| `TRANSCRIPT_REPORTED` | Recorded in the uploaded execution history, not rerun here and not proof of current source availability. |
| `LIVE_REVALIDATED` | Reserved for new checks tied to actual files, hashes, output and time on the receiving system. None assigned here. |
| `UNKNOWN` | Not established by the supplied material. |

## Available archive

| Item | Observed value |
|---|---|
| Name | `nmr-instrument.zip` |
| SHA-256 | `5b47c19c3b04185bcf76827f23cc0bc47bf2260fd1638702b030e88a8a95b8ba` |
| Size | 13,750,572 bytes |
| ZIP entries | 359, including directories and Git metadata |
| Root | `nmr-instrument/` |
| Branch | `main` |
| HEAD | `0914edbc5f9424503e6046394dd632a815474fc3` |
| Refs | `main`, `origin/main`, symbolic `origin/HEAD`; no v2 reference observed |
| Content outside `.git` | 160 files, all tracked in the archived index |
| Index comparison | 48 byte-identical; 112 differ only by CRLF/LF; no other content differences found |
| Git object check | One unreachable blob; no unreachable v2 commit reported |

The line-ending comparison does not authorize resetting or normalizing a different live checkout.

Present: `README.md`, `index.html`, `simulator/`, `mechanical/`, `fabrication/`, `hardware/README.md`, `tools/handin.py`, `.nojekyll`, `.git/`.

Absent from the uploaded snapshot: `legacy/`, `design/`, `generated/`, `physics/`, `pulse/`, `firmware/`, `tests/`, `docs/audit.md`, `validation/legacy-audit/` and the earlier proposed orchestration/handoff documents. See `snapshot-manifest.json` for all 160 file fingerprints.

## Later transcript progress

| Phase | Recorded work | Original transcript lines | In ZIP? |
|---|---|---|---|
| M0 | Electronics, firmware/host/DSP and physics agents returned detailed audits; checks/builds reported | 3920–4414 | No audit artifacts; reports preserved here as historical evidence |
| v2 separation | New branch; old site/CAD/simulator moved into `legacy/` | 4457–4473 | No |
| M1 | YAML, schema, generator, generated files and 12 passing config tests | 4598–5310 | No |
| M2/M3 | C++20 physics/DSP, pulse IR/compiler/validator/codec, simulation, C ABI, Python binding, tests | 5311–8617 | No |
| WASM | Shared-core build, JS loader/ABI checks, one native/WASM parity test | 8618–9077 | No |
| M4 planner | Shared pulse backend and 20 planner checks; selected suites rerun after rate changes | 9104–9478 | No |
| M4 firmware WIP | PlatformIO/ESP-IDF project, shared components, gate engine, ADC streamer, RF component | 9078–10746 | No |
| Interruption | RF component registration and I2C header lookup immediately before usage-limit message | 10737–10747 | Historical stopping point |

## Commit locators from the transcript

| Prefix | Recorded checkpoint |
|---|---|
| `b61c1e9` | M0/M1 audit, legacy migration, canonical model and tests |
| `1223c06` | LF policy for generated-file checks |
| `de1a13f` | Corrected M2/M3 checkpoint after fixing a failed duplicated-constant test |

These are lookup hints, not available commits in this ZIP or verified remote refs. `85d58a3` was amended and should not be preferred over the corrected checkpoint. A later WASM commit command is recorded without its resulting hash. Subsequent firmware work may be uncommitted. **Recover WIP separately from commits.**

## Exact interruption point

Last recorded working area: `C:/Users/Liang/tigp-2026/nmr-instrument/firmware`.

Relevant final files:

```text
firmware/components/engine/include/engine.hpp
firmware/components/engine/engine.cpp
firmware/components/adc/include/adc_stream.hpp
firmware/components/adc/adc_stream.cpp
firmware/components/adc/CMakeLists.txt
firmware/components/rf/include/rf.hpp
firmware/components/rf/rf.cpp
firmware/components/rf/CMakeLists.txt
```

The transcript announces a fractional-delay I/Q sampling-skew correction and firmware main control loop as upcoming work. The last RF header/API lookup is **not** an end-to-end firmware build result. No complete new-firmware build/flash/bench result is established after those final writes.

## Hardware state

The archive README states design stage and no physical measurements. Later the user says an ESP32 was connected; serial enumeration reports `COM6`, VID `303A`, PID `1001` (lines 5049–5063). Still later the session identifies an N16R8 configuration from project information (9547–9586).

These are historical observations. Do not repeat the earlier “no board connected” statement as current fact. A connected USB device is not flash authorization, an electronics test or evidence of an FID. No measured NMR FID, spectrum or spin echo is evidenced in the supplied materials.

## Ownership

The archive's `README.md` and `hardware/README.md` keep the existing class-board hardware/firmware in the shared course repository, pinned to `eef00d20a10deca994a8efe07c588c22af2b9db0`. The later rewrite starts experimental firmware in `nmr-instrument/v2`.

Preserve both facts: v2 is a successor under development, not an approved replacement for the instructor's repository. Document the integration boundary when the live rewrite is recovered; do not silently overwrite the class-board firmware.

## Next operation

Read-only discovery of the live checkout, its uncommitted files, relevant refs and worktrees. Follow `RECOVERY_PLAN.md`, then `NEXT_ACTIONS.md`. Do not restart the project or replay the legacy migration.

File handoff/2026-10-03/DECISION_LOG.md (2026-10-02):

# Decision Continuity Register

## Scope

This is a register of decisions/proposals visible in the supplied material, not a new set of approved ADRs. The transcript references ADR-0004 through ADR-0009, but the ZIP contains no `design/adr/` and the transcript does not establish that all those ADR files were written. Locate live ADRs before assigning approved status.

The user wants a from-scratch successor retaining useful work and progressing to real sample measurements. Account recovery is not a request for another restart of work already completed on v2.

## Recorded architectural direction

| Topic | Recorded direction | Evidence and limitation |
|---|---|---|
| Repository separation | Move old site/CAD/simulator under `legacy/` on `v2`, preserve main | Transcript L4457–4473. Not present in the ZIP. Do not replay against recovered v2. |
| Config | YAML quantities with value/unit/kind/source; generated C++/JSON/Python | L4598–5310, later amended. Canonical design values are not automatically measured facts. |
| Numerical core | C++20 physics/DSP, C ABI, Python wrapper, same sources built to WASM | L5311–9077. Keep reference tests and performance claims separately traceable. |
| Pulse system | Hardware-independent IR/compiler/validator/codec and backend planner | L5537–6134; L9216–9478. Read interfaces before adding experiments. |
| Real-time gates | RMT waveforms; MCPWM capture/timestamps | L9592–10383. Written source/header inspection is not measured determinism. |
| ADC | Proposed I2S/DMA framing instead of CPU-paced Arduino SPI | L9146–9208; L10384–10584. Protocol suitability and actual timing remain verification tasks. |
| Phase reference | Proposed DDS SIGN BIT and LO_I capture inputs, marked ECO-1 | L9182–9184; L10585–10610. Wiring must be checked, not assumed. |
| Firmware ownership | Experimental successor in `nmr-instrument/v2`; existing class-board implementation remains authoritative for the current board | Archive README/hardware README versus later rewrite. Document eventual integration separately. |
| Mechanical | STEP/BREP intended for successor; useful OpenSCAD/assets retained | User mission and historical audit. No completed successor BREP assembly is established. |

## Later numeric choices — do not revert by copying an early Write

These are historical design choices only. Inspect live YAML and provenance before using them.

| Quantity | Earlier value | Later recorded change | Meaning |
|---|---|---|---|
| t90 / t180 | 417 / 834 microseconds | 458 / 916 microseconds | L5111–5146, calculated with a proposed 0.7 V TX series-diode drop, not measured nutation calibration |
| Acquisition duration | Legacy firmware default 2 s | v2 target 0.5 s | M1 choice, not a second independent default to maintain |
| Raw rate / decimation | 100 kS/s per channel / 4 | 125 kS/s per channel / 5 | L9146–9208; both target 25 kS/s complex output; hardware operation unverified |
| ADC framing | CPU-paced 32-bit SPI | Proposed 16 MHz clock, 64-bit frame, one conversion per frame | Recorded rationale; actual framing and ADC timing require validation |
| Flash/PSRAM | Initial 8 MB flash config | Later reported N16R8, 16 MB flash / 8 MB octal PSRAM | L9547–9586; verify final configuration and actual board |
| Gyromagnetic ratio | Legacy rounded value | Source-qualified shielded-proton value in v2 YAML | Preserve convention/provenance; do not mix constants silently |

## Historical statements that need careful handling

The audits mix source observations, calculations, estimates and remedies. Preserve those evidence types. In particular, the early statement that a shared-coil problem necessarily causes firmware to abort is not a safe inherited fact: the later audit reports the relevant amplifier fault pins as unwired. Keep the safety concern without implying a working interlock.

The transcript distinguishes worst-case field range, record/window-limited FWHM and envelope decay. Do not revive earlier superseded linewidth estimates as golden targets.

Do not silently “correct” hardware topology, sign convention, ADC framing or safety requirements during handoff preparation. Resolve them explicitly against live sources and independent tests during continuation.

## Changing a decision after recovery

Record actual inputs, alternatives, rationale, affected interfaces/tests/hardware and validation evidence. Preserve superseded decisions. Use real live ADR paths rather than inventing approved ADR identifiers.

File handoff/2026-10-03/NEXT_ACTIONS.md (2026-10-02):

# Exact Next Actions

## Entry condition

First recover and protect the v2 sources under `RECOVERY_PLAN.md`. With only the supplied main snapshot, source recovery is the next task; M4 implementation cannot truthfully be called resumed yet.

## 1. Establish the live baseline

Inspect current project instructions, build files, dependencies, generated representations and actual ADRs. Capture HEAD, WIP and config/source hashes. Verify config freshness, native build/tests, Python tests and native/WASM parity against the same configuration.

The later change to 125 kS/s and decimation 5 occurred after the first parity result. A stale WASM binary must not be accepted because it exists. Record unavailable toolchains as `NOT_RUN`, not `PASS` or an instrument failure. Inspect installed versions before installing anything.

## 2. Resume Milestone 4 at the firmware integration boundary

Read these actual paths first:

```text
firmware/platformio.ini
firmware/CMakeLists.txt
firmware/sdkconfig.defaults
firmware/main/
firmware/components/engine/include/engine.hpp
firmware/components/engine/engine.cpp
firmware/components/adc/include/adc_stream.hpp
firmware/components/adc/adc_stream.cpp
firmware/components/rf/include/rf.hpp
firmware/components/rf/rf.cpp
firmware/components/*/CMakeLists.txt
pulse/include/pulse/backend.hpp
pulse/src/backend.cpp
physics/include/nmr/pipeline.hpp
physics/src/pipeline.cpp
design/instrument.yaml
generated/instrument_config.hpp
```

Check whether newer live work already fills `firmware/main/`. Preserve it. Otherwise finish the main/control entry point around the existing components rather than writing new duplicate drivers.

### FW-RESUME-01 — Main/control integration

Implement and verify pre-arm configuration/program checks; safe idle/configured/armed/running/complete/abort/fault transitions; control-plane RF setup and bus ownership; gate/acquisition/capture coordination; preallocated buffers and explicit capacity limits; visible incomplete-record/overflow errors; and safe outputs after initialization/API/abort failures.

Map these requirements to any state model already implemented. Use the shared DSP pipeline and reliable record identity/metadata rather than another independent DSP or stale-frame path. These are acceptance conditions, not claims the partial firmware satisfies them.

### FW-RESUME-02 — Pending I/Q sampling-skew correction

The final session explicitly proposes a fractional-delay correction after estimating about 7.8 degrees of I/Q skew. Keep the number labeled as a prior estimate.

Establish conversion order, per-channel aperture times, frame layout and timestamp meaning from the recovered driver and applicable ADC documentation. Implement and test correction consistently in the shared pipeline and simulator, exactly once. Include positive/negative tone offsets, channel order/sign, transient boundaries and replay tests. Do not declare physical I/Q alignment validated without measurements.

### FW-RESUME-03 — Complete firmware build

Run the live project's declared build after integration, capturing the unfiltered exit code and log. The final I2C header lookup is not a complete build result.

Fix compile/link/configuration errors before claiming an executable firmware milestone. Inspect final flash/PSRAM settings: the transcript begins with an 8 MB default and later uses a reported N16R8 configuration. The first Write of a config file is not its final state.

### FW-RESUME-04 — Hardware verification plan, not invented results

Prepare finite gate-timing, capture/phase, ADC-framing/throughput, recovery and known-tone loopback tests. Check board connection afresh; COM6 is historical.

Do not flash or energize merely because the new session has access. Preserve existing board firmware and obtain explicit flashing authorization. GPIO values for proposed ECO inputs do not establish that wires exist.

## 3. Keep the other instrument blockers visible

T/R isolation/protection, B0 stability, fault wiring, receiver behavior and probe calibration remain separate from software compilation. Parallel reviewers may investigate these under disjoint write ownership.

## Do not redo indiscriminately

Do not repeat the full legacy audit, recreate the generator, replace the pulse IR, discard maps, or reorganize CAD/site paths merely because the new agent lacks the old chat. Rerun targeted checks when inputs changed, evidence is absent or contradictions exist.

A firmware build is not measured jitter, ADC throughput, TX/RX isolation, stable B0, calibrated probe, an FID, spectrum or echo. Preserve those experimental gates separately.

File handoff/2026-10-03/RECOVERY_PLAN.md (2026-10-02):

# Recovery Plan — Preserve First, Resume Second

## A. Inspect the actual live checkout

Start with the known project locations, if present:

```text
C:/Users/Liang/tigp-2026/nmr-instrument
C:/Users/Liang/tigp-2026/class-board-2026
```

Do not search unrelated personal folders by default. Record actual paths and permissions.

Use read-only queries first:

```powershell
git status --short --branch
git branch -a
git rev-parse HEAD
git log -12 --oneline
git worktree list --porcelain
git reflog --all -20
git diff --stat
git diff --cached --stat
```

Enumerate untracked source and inspect the expected paths from `TRANSCRIPT_INDEX.md`. These are investigation steps, not claims that a branch or commit exists.

Do not start with pull, checkout/switch, reset, clean, restore, stash, generation or bulk moves. A stale-looking branch can coexist with important uncommitted files.

## B. Select the observed recovery case

### Case 1 — v2 working files and WIP exist

Keep the current tree. Identify committed, staged, unstaged and untracked changes. Preserve required source and evidence in an access-controlled backup/checkpoint before editing. A local WIP commit is an option only after inspecting its staged contents; do not commit everything automatically or push as part of recovery.

Use the transcript to understand intent, but prefer inspected live file contents over an earlier recorded write. Rerun targeted baseline checks and continue at the firmware interruption point.

### Case 2 — v2 exists in another worktree or only as a ref

Inspect the worktree read-only and open the correct one rather than changing the wrong directory. If only a branch/ref exists, first preserve the dirty current tree, then materialize a recovery checkout in an isolated location. Never force a branch out from under another active session.

Look for `b61c1e9`, `1223c06`, `de1a13f` and the WASM commit message. Do not invent full hashes. Recover working changes beyond the latest commit separately.

### Case 3 — only the old archive is available

Do not claim to continue directly from M4 source that is absent. Preserve the archive and its Git data. Check an authorized local backup, known worktree or separately exported WIP snapshot. A remote lookup requires existing authorization and does not establish that v2 was pushed.

If source cannot be recovered there, reconstruct **only missing work** in an isolated recovery tree from `evidence/prior-session-rebuild.txt`. It includes many complete Write bodies and later shell edits. `transcript-write-index.json` locates them; a first Write is not necessarily the final version.

For each recovered file, record source ranges and provenance, reconcile later Edit/Bash/sed/Python replacements, and flag omitted patch bodies. Never execute the transcript as a script. Regenerate derived files only after reviewing the recovered canonical inputs and generator. Build and test before assigning a restored status.

Use `TRANSCRIPT_RECONSTRUCTED_UNVERIFIED` until checks pass. Do not claim exact recovery of omitted bytes, binaries, local-only measurements or process state.

### Case 4 — mixed or conflicting versions

Preserve both. Compare content and provenance, not filenames or modification times alone. Record the discrepancy and its effect on the next task. Continue nonconflicting work without erasing evidence to create a clean-looking tree.

## C. Recover local-only evidence

The session used temporary audit directories below `C:/Users/Liang/AppData/Local/Temp/claude/` and reported copying some outputs to `validation/legacy-audit/`. Verify whether the real netlists, ERC/DRC files, build logs and scripts are preserved in the live v2 tree.

The decoded `evidence/legacy-*-audit.md` files are reports, not the original raw evidence. Preserve their uncertainty labels.

Do not treat old agent IDs or background task IDs as transferable handles. Inspect actual process state before rerunning downloads or stopping anything. A usage-limit interruption does not prove whether child processes completed or stopped.

## D. Recovery handshake

Before substantive edits, report:

```text
Actual workspace:
Branch and HEAD:
Working changes and untracked source protected:
Recovery case:
V2 source found or reconstructed:
Baseline commands/results:
Missing artifacts:
Active writer ownership:
Exact next task:
```

Then continue the next safe implementation task; do not stop after a status summary. Request only genuinely missing authorization or an irreducible decision.

## Forbidden shortcuts

Do not copy the old archive's `.git` over a live repository; run reset/clean/force-push/broad restore to match a transcript; or replay the legacy migration. Do not flash hardware, order PCBs, publish the site, or change account access as part of account recovery without the relevant authorization.

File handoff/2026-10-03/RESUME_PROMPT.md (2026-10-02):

# Prompt to Paste Into the New Coding-Agent Session

You are taking over an existing benchtop NMR instrument rewrite after an account/session interruption. Continue the existing work; do not restart the project or merely produce another proposal.

Open the authorized live `nmr-instrument` folder. The previous session used `C:/Users/Liang/tigp-2026/nmr-instrument`; verify the actual path.

Read `RESUME_AFTER_ACCOUNT_SWITCH.md`, then `handoff/2026-10-03/CURRENT_STATE.md`, `RECOVERY_PLAN.md`, `NEXT_ACTIONS.md`, `OPEN_ISSUES.md`, `DECISION_LOG.md`, `TEST_EVIDENCE.md` and `AGENT_TASKS.md`. Inspect existing live project instructions and actual ADRs too.

Critical discrepancy: the uploaded ZIP inspected for this handoff is legacy `main` at `0914edbc5f9424503e6046394dd632a815474fc3`. The attached execution record describes later v2 canonical configuration, shared C++ physics/DSP, pulse IR/compiler/backend, Python/WASM interfaces, tests and partial ESP-IDF firmware. Those v2 files are absent from that ZIP. They may still be in the live checkout, another worktree, local commits or a backup. Never overwrite newer live files or `.git` with the old archive.

Before editing, inspect actual branch/HEAD, relevant refs/worktrees, staged/unstaged changes, untracked source, saved evidence and installed toolchains. Use the included `capture_state.py` as a read-only aid. Protect WIP and select the recovery case. Do not reset, clean, force-push, rerun the legacy migration, or change account credentials. Do not treat old agent/task IDs as portable state.

The final recorded operation registered `firmware/components/rf` and checked I2C API symbols. Gate-engine and ADC-streamer source had been written. The firmware main/control loop and a planned I/Q sampling-skew correction are the continuation area. The transcript does not establish a complete new-firmware build or physical measurement. Check for newer live changes before duplicating work.

Preserve the physics-driven instrument mission and useful features. Keep archive observations, historical reports, live tests, estimates and measurements distinct. Do not repeat the complete legacy audit unless inputs changed or evidence is missing. Do not label proposed T/R, B0, phase-reference wiring or I2S ADC changes as bench-validated.

Report a compact recovery handshake: actual workspace/source state, v2 work available, transcript-only claims, baseline checks, open blockers, write ownership and exact next action. Then implement and test the next safe task in `NEXT_ACTIONS.md` and save a checkpoint. Do not stop at a summary. If the v2 source truly cannot be located, use the isolated, provenance-tracked reconstruction path in `RECOVERY_PLAN.md`; do not invent missing bytes or results.

Do not flash hardware, energize an unverified setup, publish the site, order boards or push remotely without the relevant explicit authorization. Save important reports and logs to durable project files so the next session does not depend on this account's memory.

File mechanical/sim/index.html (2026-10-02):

# NMR bench setup

proton line 89.4 kHz · B0 2.10 mT · class coil 400 T AWG26, 2.53 mH · Helmholtz pair R 200 mm, 1.5 A

Overview Probe Housing Top

Point at a part

Drag to orbit, scroll or pinch to zoom, click a part to centre on it.

Thermal equilibrium: M along B0
Frame rotating at f_tx. Fire a pulse to start the clock.

Loading the bench…

## Pulse experiment

Fire pulse

Where the sample is: water in a 50 mL tube, pushed into the coil from its open end through the sleeve until the cap stops at the flange; the water fills x −58 … +45 mm of the 100 mm winding (the bottle fills the whole bore). In the 3D view each short arrow is one of 400 simulated water voxels at its real place, pointing along its magnetization: grey along B0, coloured by precession phase once tipped.

Pulse length417 µs f_tx89 400 Hz B0 current1.500 A Earth ∥ B00 µT

Sample

50 mL tubeBottle, full bore

Averages

141664

Receiver I channel, ADC volts25 kS/s, IF 5.4 kHz

Spectrum of the 200 ms record

B0 field and coil axis Magnetization of the water voxels See inside the probe Turn the bench slowly

## Assembly

Housing

Laser-cutPrinted

Exploded view0 %

## Checks

- stopTX and RX on one coil The RX diodes clamp at ±0.7 V across the transmitter's ±7.95 V: 1.54 A through R813 trips the OPA564's 1.5 A limit on the first pulse. Needs a board-side decision (TX diodes + RX series element, or a second, crossed receive coil).
- mindSignal size The 50 mL tube gives 0.83 µV at the coil, 8.1 µV at the tank: a fifth of the 40 µV the receiver was sized for (TeachSpin's estimate). ADC peak 0.21 V, single-sample SNR 4. Average, or use the full-bore bottle (15 µV).
- mind90° pulse length The workbook's 417 µs assumes an endless solenoid. This coil (length 2.4 × its diameter) gives 13.0 µT rotating at its centre: 90° takes 451 µs; 417 µs tips 83°.
- okB0 homogeneity Worst case 1688 ppm at the winding ends, but most of the water sits where the error is under 50 ppm: simulated T2* 72 ms, line 6 Hz wide (Libbrecht's rig: about 75 ms).
- mindB0 drift Voltage-driven, 23 W warms 9.2 kg of copper by 0.39 K/min: the line falls 138 Hz/min, 7 Hz between averaged scans against a ~2 Hz line. Drive B0 at constant current, or measure it each scan and correct f_LO.
- okRX tank with the coax 0.78 m of RG174 adds 79 pF. Fit C710 only: tank at 88.47 kHz (−0.18 dB). All three fitted: 84.53 kHz (−3.4 dB). Or set B0 to 1.484 A.
- okB0 drive 15.6 V of the 18 V rail at 1.5 A of the H-bridge's 2 A trip.
- okSteel near the sample Nearest steel screw 492 mm away; the rings (r 217 mm) clear the housing.
- okCables TX pair 590 mm · RX coax 784 mm · B0 leads 1011 mm, with 15 % slack.

Built from instrument.scad, probe.scad, housing.scad and cut-housing.scad (docs/students/yi-tsai/housing), 2 Oct 2026. The pulse experiment solves the Bloch equations for 3000 voxels of the sample in the B0 pair's real field (4th-order Helmholtz error, the Earth's field), the coil's finite-solenoid B1, reciprocity pickup, the Q = 10 tank and the receiver noise (15.6 nV/√Hz over 15 kHz). It is shown in the frame rotating at f_tx: in the lab the magnetization turns 89 400 times a second.

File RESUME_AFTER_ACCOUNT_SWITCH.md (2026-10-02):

# Resume the NMR Rewrite After an Account Switch

Read this before editing.

The handoff was prepared from `nmr-instrument.zip` and the attached execution transcript. **They describe different states.** The ZIP is `main` at `0914edbc5f9424503e6046394dd632a815474fc3`; the transcript records later v2 work through partial ESP-IDF firmware. This package is not a verified backup of that missing working tree.

Read [Current state](handoff/2026-10-03/CURRENT_STATE.md), follow [Recovery plan](handoff/2026-10-03/RECOVERY_PLAN.md), then use [Exact next actions](handoff/2026-10-03/NEXT_ACTIONS.md), [open issues](handoff/2026-10-03/OPEN_ISSUES.md) and [test evidence](handoff/2026-10-03/TEST_EVIDENCE.md).

The recorded original path is `C:/Users/Liang/tigp-2026/nmr-instrument`; verify it. Do not overwrite it with the old ZIP, replace its `.git`, discard WIP, or replay the legacy migration.

The stopping point is **firmware integration after RF component registration**, not “finish the YAML generator.” The latter was followed by native/Python tests, WASM work, backend planning and several firmware components in the transcript.

The [copy-paste prompt](handoff/2026-10-03/RESUME_PROMPT.md) contains takeover instructions. [Installation](handoff/2026-10-03/README.md) explains safe placement. [Agent assignments](handoff/2026-10-03/AGENT_TASKS.md) define focused recovery, integration and review roles.

After recovery, continue actual implementation and tests. Save the next checkpoint using the [template](handoff/2026-10-03/CHECKPOINT_TEMPLATE.md). An account/session change must not erase progress or turn unmeasured claims into facts.

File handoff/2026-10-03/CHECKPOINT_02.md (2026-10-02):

# Live Handoff Checkpoint 02

> Live-verified on the receiving machine (LIVE_REVALIDATED). Follows CHECKPOINT_01.

## Identity

- Timestamp: 2026-10-03, Asia/Taipei (UTC+8)
- Workspace: `C:/Users/Liang/tigp-2026/nmr-instrument`
- Branch / HEAD: `v2` @ `2323d04` (pushed; `local == origin/v2`)
- Config hash: `5469d421b230e04050b1857e02686054efc885e866bb7cbee033ac091047e0a4` (unchanged; `gen_config --check` up to date)
- Backup: pushed to `origin/v2` (github.com/tojestspacja/nmr-instrument); local `v2-backup-pre-rewrite` kept.
- Commit identity: GitHub noreply `171763498+tojestspacja@users.noreply.github.com` (privacy + push protection ON).

## Work since CHECKPOINT_01

**FW-IQ-001 done** (`2323d04`): I/Q aperture-skew correction implemented once in the shared DSP.
- `dsp::frac_delay` — centred windowed-sinc fractional-delay FIR.
- `PipelineConfig.iq_skew_samples` (opt-in, default 0 → C ABI / WASM parity untouched); I delayed onto Q's grid.
- `InstrumentModel.iq_skew_samples` — simulator models the skew; the skew==0 path is bit-identical (RNG order preserved).
- firmware controller sets it from channel order (+0.5, ch_i>ch_q).
- `physics/tests/test_iq.cpp` (13 checks) — see evidence.

Also pushed earlier this session: Case-1 recovery + WIP protection, SIM-PARITY-001 (WASM rebuild), FW-RESUME-01/-03
(firmware main control loop + it builds). See CHECKPOINT_01.

## Evidence (LIVE_REVALIDATED, 2026-10-03)

| Command | Result |
|---|---|
| `cmake --build build && ctest` | 7/7 suites pass (test_iq: skew err 7.5e-2 uncorrected → 3.6e-4 corrected; wrong-sign worse) |
| `py -m pytest -q tests` | 16/16 (incl native/WASM parity, duplicated-constant guard) |
| `py simulator/wasm/build.py` | nmrcore.wasm 395 KiB, config sha matches |
| `pio run -d firmware -e esp32s3` | [SUCCESS], RAM 8.1% (26544 B), Flash 7.8% (326007 B) |

## Issues

- Closed in session: SIM-PARITY-001, FW-RESUME-01, FW-RESUME-03, FW-IQ-001.
- Still open: FW-ADC-001, SYS-PHASE-001, HW-TXR-001, HW-B0-001, HW-SAFE-001, HW-INTEGRATION-001, NMR-EVIDENCE-001
  (all hardware/bench — unchanged by software), and DOCS-ADR-001 (no `design/adr/`; ADR-0004..0009 are referenced but
  not files).
- Hardware actions authorized/performed: none.

## Next agent's first task

Software options, pick one and scope it:
(a) DOCS-ADR-001 — write `design/adr/ADR-0004..0009.md` as retrospective records of decisions already in the code
    (tick/IR, RMT gates, ADR-0006 phase, ADR-0007 TX diodes, ADS8688 I2S). Do NOT fabricate historical approvals.
(b) Expose `iq_skew_samples` through the C ABI (`nmr_pipeline`) + JS loader so the browser simulator can demonstrate the
    skew/correction too; update `nmr_abi_layout` consumers and re-verify WASM parity.
(c) A console program-loader for the firmware (decode an NMRP program over USB-serial) instead of the built-in default.

The instrument blockers (TX/RX isolation, B0 stability, phase-reference closure, real FID) are hardware and remain the
true gates; keep them separate from software milestones. Completion test for any software task: `ctest` + `pytest` stay
green, WASM rebuilt and parity passes, firmware still builds.

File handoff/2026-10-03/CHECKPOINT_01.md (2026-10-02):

# Live Handoff Checkpoint 01

> Live-verified. Every result here was produced on the receiving machine this session (LIVE_REVALIDATED), not copied
> from the transcript. Historical/transcript claims stay in the 2026-10-03 handoff docs.

## Identity

- Timestamp with timezone: 2026-10-03, Asia/Taipei (UTC+8)
- Actual workspace: `C:/Users/Liang/tigp-2026/nmr-instrument`
- Branch and full HEAD: `v2` @ (this checkpoint's commit; parents below)
- Config hash: `5469d421b230e04050b1857e02686054efc885e866bb7cbee033ac091047e0a4` (`gen_config.py --check` = up to date)
- Parent handoff: `handoff/2026-10-03/CURRENT_STATE.md`
- Recovery case: **Case 1** — the live v2 working tree and WIP were present and intact; no reconstruction needed.
- Access-controlled backup/checkpoint: local commits only. **Not pushed to any remote** (origin has only `main` @ `0914edb`). Off-disk backup still OWED.

## Recovery handshake (resolved)

The 2026-10-03 handoff was built from an older `main`-snapshot ZIP, so it treated "v2 source lost" (HANDOFF-001) and
"raw validation artifacts lost" (HANDOFF-002) as blockers. Live inspection disproved both: branch `v2`, the full commit
chain `b61c1e9 -> 1223c06 -> de1a13f -> 93a0c84`, all source, and `validation/` (DRC/ERC json+rpt, golden fieldmaps,
legacy-audit scripts) are present. Only the WASM binary was stale, and `firmware/main/` was empty.

## Work done this session

1. Protected the as-found WIP verbatim before editing (`7649f41` code, `5794b56` handoff docs).
2. **SIM-PARITY-001 closed** (`5968d6b`): the committed `nmrcore.wasm` embedded config `b759cbb0...`, native was
   `5469d421...`; rebuilt WASM from current sources (393 KiB), parity now passes.
3. **FW-RESUME-01 + FW-RESUME-03** (`11c074e`): wrote `firmware/main/` (control state machine + experiment sequencer)
   and fixed two build blockers (`default_16MB.csv` partition table; `adc_stream.hpp` volatile `++`). Firmware builds.

## Working files

| Path | State | Intent/completeness | Owner | Backup |
|---|---|---|---|---|
| `firmware/main/{controller.hpp,controller.cpp,main.cpp,CMakeLists.txt}` | committed `11c074e` | FW-RESUME-01 complete; builds; NOT bench-validated | this session | local commit only |
| `firmware/default_16MB.csv` | committed `11c074e` | N16R8 partition table | this session | local commit only |
| `firmware/components/adc/include/adc_stream.hpp` | committed `11c074e` | volatile-`++` build fix | this session | local commit only |
| `simulator/web/nmrcore.wasm` | committed `5968d6b` | rebuilt from current config | this session | local commit only |
| `firmware/sdkconfig.esp32s3` | gitignored | PlatformIO-generated build output | — | n/a |

Working tree is clean. An empty diff here means committed, **not** backed up off this disk.

## Evidence checked in this session

| Command | Source/config identity | Result | Raw log |
|---|---|---|---|
| `py tools/gen_config.py --check` | config `5469d421` | up to date (exit 0) | stdout |
| `cmake -S . -B build -G Ninja && cmake --build build` | HEAD v2 | build OK (exit 0) | `/tmp/build.log` (transient) |
| `ctest --test-dir build` | HEAD v2 | 6/6 PASS (bloch, field, dsp, pulse, sim, backend) | stdout |
| `py -m pytest -q tests` | HEAD v2 | 16 passed | stdout |
| `py simulator/wasm/build.py` | config `5469d421`, wasi-sdk 25 / clang 19 | wrote `nmrcore.wasm` 393 KiB (exit 0) | stdout |
| `py -m pytest -q tests/test_wasm_parity.py` | native+WASM both `5469d421` | 1 passed (config sha match, I=Q=0 LSB) | stdout |
| `pio run -d firmware -e esp32s3` | HEAD v2, espressif32@7.1.2 / ESP-IDF 6.1.0 | **[SUCCESS]** RAM 8.1% (26544 B), Flash 7.8% (325155 B) | task log `b7cq1lknu.output` |

Toolchain seen: Python 3.11.5, CMake 3.31.5, Ninja 1.12.1, g++ 14.2 / clang 19.1.7, Node 24.15, PlatformIO 6.2.0.
`idf.py` not on PATH; ESP-IDF is used via PlatformIO's `.espidf-6.1.0`.

## Issues and decisions

- Closed this session: SIM-PARITY-001; FW-RESUME-01, FW-RESUME-03.
- Downgraded (live-disproven): HANDOFF-001, HANDOFF-002.
- Still open (unchanged): FW-IQ-001 (I/Q aperture skew, below), FW-ADC-001, SYS-PHASE-001, HW-TXR-001, HW-B0-001,
  HW-SAFE-001, HW-INTEGRATION-001, NMR-EVIDENCE-001, DOCS-ADR-001 (no `design/adr/` exists; ADR-0004..0009 referenced
  in code/comments are not files).
- Hardware actions authorized: **none**. No flashing, no energising performed or requested.

## FW-IQ-001 — scoped, not yet implemented

ADS8688 AUTO_SEQ delivers Q (ch 2) then I (ch 3), so within each complex sample I is sampled one conversion period
(1 / 250 kHz = 4 us) after Q. At the 5.4 kHz IF that is 4 us x 5400 Hz x 360 deg = ~7.8 deg of I/Q phase skew — matching
the transcript's estimate. Correction (a fractional-delay realignment) belongs once in the shared `physics/src/pipeline.cpp`
and the simulator, with tests for sign, channel order, +/- tone offsets, transient boundaries and replay. The firmware
controller deliberately does NOT apply it and claims no I/Q alignment.

## Next agent's first task

Implement FW-IQ-001 in the shared pipeline. Inputs: `physics/src/pipeline.cpp`, `physics/include/nmr/pipeline.hpp`,
`physics/src/dsp.cpp`, the simulator record generator, and a new/extended test under `physics/tests/`. Permitted writes:
those paths + `firmware/` only if an interface changes. Completion test: a host test shows a known-tone's recovered phase
corrected to within tolerance for both tone signs, `ctest` stays 6/6 (+ the new case), `pytest` 16+ passes, and native/WASM
parity still passes after rebuilding the WASM. Do NOT claim physical I/Q alignment without bench measurement.

Also OWED and separate: push `v2` off-disk (no backup exists yet) — requires the user's go-ahead.

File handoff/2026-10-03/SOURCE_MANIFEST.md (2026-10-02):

# Source Manifest and Provenance

## Inputs actually used

| Input | Size | SHA-256 | Role |
|---|---:|---|---|
| `nmr-instrument.zip` | 13,750,572 bytes | `5b47c19c3b04185bcf76827f23cc0bc47bf2260fd1638702b030e88a8a95b8ba` | Available project bytes and archived Git metadata |
| `Pasted text.txt` | 654092 bytes | `c4f56a1a92747fb1d7b77dd57802df4431ef472958be1cf2dc8c7db71106579d` | 10,747-line historical execution record |

The mounted ZIP is the received file at the supplied path. Repeated uploads with the same filename cannot be distinguished by title alone; the SHA-256 identifies the exact bytes inspected.

The available `class-board-2026 (2).zip` was not used for a fresh electronics audit in this handoff. Hardware findings here are attributed to the prior agent handbacks. No live GitHub, account or Windows-machine state was fetched.

## Archive observations

Direct inspection established branch `main`, HEAD `0914edbc5f9424503e6046394dd632a815474fc3`, and no v2 branch reference or successor working directories. All 160 non-Git files match the archived index after CRLF/LF normalization; 48 match byte-for-byte and 112 have only line-ending differences. Original source bytes were not normalized or altered.

Raw metadata queries are retained in `evidence/archive-git-observation.json`. Source entry/README excerpts are in `evidence/archive-source-excerpts.txt`. The full file fingerprint list is `snapshot-manifest.json`. That list is observation evidence, not an instruction to overwrite a newer local tree.

## Transcript evidence

`evidence/prior-session-rebuild.txt` preserves original lines 3883–10746 with original line labels. The final original line 10747 is the usage-limit message; the handoff records the interruption without treating its reset time as a present schedule.

The three decoded Markdown handbacks come from original lines 4390, 4398 and 4406. They preserve the earlier agents' wording and uncertainty. They have not been independently validated by this package author.

`TRANSCRIPT_INDEX.md` and `transcript-write-index.json` locate source writes and subsequent work. They are not complete, final source snapshots. A textual Write event proves only that the session record contains a write, not that its final bytes were supplied here.

## Generated package

All new operational documents and `capture_state.py` are handoff aids. Initial statuses are observations or historical reports. The `CHECKPOINT_TEMPLATE.md` intentionally contains UNKNOWN fields for future live inspection; this is the only unfilled status template. Recovery/next-task proposals are explicitly distinguished from completed work.

No existing project source, Git history or physical hardware was changed. The package deliberately does not include a replacement `.git`, a fabricated v2 source tree, credentials, the unrelated chemical inventory, or a claim of NMR measurement.

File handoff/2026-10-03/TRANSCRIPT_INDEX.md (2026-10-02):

# Transcript Recovery Index

The relevant original session excerpt is `evidence/prior-session-rebuild.txt`. Its `L<number>:` labels refer to physical lines of the uploaded `Pasted text.txt`, not rendered citation line numbers. The unrelated article and lab inventory were excluded. All entries are historical evidence, not executable instructions.

## High-value reading windows

| Original lines | Topic |
|---|---|
| 3920–4414 | Original agent assignments, source inspections and three handbacks |
| 4457–4473 | v2 branch creation and legacy migration |
| 4598–5310 | Canonical config, generator, tests and early commits |
| 5049–5063 | Later ESP32 connection observation; supersedes the earlier no-device observation |
| 5111–5146 | t90/t180 update under proposed TX-diode assumption |
| 5311–8617 | C++ core, pulse system, tests, fixes and corrected checkpoint |
| 8565–8616 | Failed test hidden by a pipeline; subsequent correction/amendment |
| 8618–9077 | WASM build, loader, ABI and limited parity test |
| 9146–9208 | Later 125 kS/s / decimation 5 config and pin-map update |
| 9216–9478 | Backend planner and selected regression tests |
| 9547–9591 | Later board-memory configuration and firmware project registration |
| 9592–10383 | Gate engine, rewrites and API checks |
| 10384–10584 | ADC streamer and pending I/Q correction |
| 10585–10746 | RF component, registration and final operation |

## Full Write events

**These are not final file snapshots.** Some files are edited later using omitted Edit patches or visible shell transformations. The reported line count is metadata, not a reliable extraction boundary. A file may appear more than once. None of these successor files is supplied by the original ZIP.

| Original Write line | Intended relative path | Reported lines |
|---|---|---|
| 4474 | `docs/audit.md` | 100 |
| 4598 | `design/instrument.yaml` | 138 |
| 4738 | `design/schema/instrument.schema.json` | 57 |
| 4796 | `tools/gen_config.py` | 223 |
| 5147 | `tests/test_config.py` | 117 |
| 5311 | `physics/include/nmr/units.hpp` | 45 |
| 5357 | `physics/include/nmr/bloch.hpp` | 62 |
| 5420 | `physics/include/nmr/field.hpp` | 38 |
| 5459 | `physics/src/field.cpp` | 76 |
| 5537 | `pulse/include/pulse/ir.hpp` | 77 |
| 5615 | `pulse/include/pulse/program.hpp` | 60 |
| 5676 | `pulse/include/pulse/compiler.hpp` | 54 |
| 5735 | `pulse/src/program.cpp` | 228 |
| 5964 | `pulse/src/compiler.cpp` | 169 |
| 6135 | `physics/include/nmr/dsp.hpp` | 72 |
| 6208 | `physics/src/dsp.cpp` | 164 |
| 6469 | `physics/include/nmr/probe.hpp` | 48 |
| 6518 | `physics/src/probe.cpp` | 76 |
| 6596 | `physics/include/nmr/sim.hpp` | 72 |
| 6669 | `physics/src/sim.cpp` | 227 |
| 6912 | `physics/include/nmr/pipeline.hpp` | 47 |
| 6960 | `physics/src/pipeline.cpp` | 58 |
| 7026 | `physics/include/nmr/capi.h` | 100 |
| 7127 | `physics/src/capi.cpp` | 270 |
| 7398 | `CMakeLists.txt` | 46 |
| 7446 | `physics/tests/check.hpp` | 30 |
| 7477 | `physics/tests/test_bloch.cpp` | 112 |
| 7590 | `physics/tests/test_field.cpp` | 74 |
| 7671 | `physics/tests/test_dsp.cpp` | 85 |
| 7757 | `physics/tests/test_pulse.cpp` | 125 |
| 7901 | `physics/tests/test_sim.cpp` | 145 |
| 8047 | `physics/benchmarks/bench_core.cpp` | 71 |
| 8238 | `validation/physics/golden/README.md` | 13 |
| 8263 | `tools/nmrpy/__init__.py` | 199 |
| 8463 | `tests/test_golden.py` | 57 |
| 8629 | `simulator/wasm/build.py` | 50 |
| 8800 | `simulator/web/nmrcore.js` | 191 |
| 9216 | `pulse/include/pulse/backend.hpp` | 65 |
| 9282 | `pulse/src/backend.cpp` | 107 |
| 9391 | `physics/tests/test_backend.cpp` | 77 |
| 9592 | `firmware/components/engine/include/engine.hpp` | 78 |
| 9671 | `firmware/components/engine/engine.cpp` | 180 |
| 10181 | `firmware/components/engine/engine.cpp` | 201 |
| 10384 | `firmware/components/adc/include/adc_stream.hpp` | 56 |
| 10441 | `firmware/components/adc/adc_stream.cpp` | 136 |
| 10585 | `firmware/components/rf/include/rf.hpp` | 25 |
| 10611 | `firmware/components/rf/rf.cpp` | 125 |

## Additional files written by shell commands

Important files also appear in Bash here-documents or generated output, including `.gitignore`, `.gitattributes`, `generated/instrument_config.*`, `tests/wasm_parity.mjs`, `tests/test_wasm_parity.py`, `firmware/platformio.ini`, firmware/shared-component `CMakeLists.txt` files and `firmware/sdkconfig.defaults`. Search the excerpt by path; the Write-event list is not a complete source manifest.

## Reconciliation hazards

The generator has an Edit event after its initial write; YAML is changed repeatedly; fields/voxel weights/tests are patched; the WASM linker script is reworked; the gate engine is rewritten more than once. Do not recover first-write source and call it the final passing checkpoint.

The last event writes the RF CMake registration and searches API names. The transcript ends at the account/session limit without a final firmware build or handoff checkpoint.

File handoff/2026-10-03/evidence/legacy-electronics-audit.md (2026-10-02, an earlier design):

# Historical Electronics Agent Handback

> Evidence class: TRANSCRIPT_REPORTED. The previous agent's report follows verbatim, decoded from the uploaded session record. It was not rerun or independently certified during handoff preparation. Estimates, uncertainties and unresolved issues remain in force; later source evidence may supersede it.

Source: `Pasted text.txt`, original line 4406. SHA-256: `c4f56a1a92747fb1d7b77dd57802df4431ef472958be1cf2dc8c7db71106579d`.

---

# Electronics audit: class-board-2026 (branch w1-yi-tsai, HEAD da56d2b)

I changed nothing in the repo; `git status` is clean. Most connectivity below comes from the netlist exported from the current schematic. Where the generator scripts or docs disagree with it, the netlist wins and the conflict is listed under §7.

## 1. ERC, DRC and netlist (KiCad 10)
No library variable was needed: the lib tables use `${KIPRJMOD}`. All runs succeeded.

| Run | Errors | Warnings | Detail |
|---|---|---|---|
| ERC main | 0 | 2 | Two `pin_to_pin` warnings: J13 (Unspecified pin type) to R933 / GND. Cosmetic. |
| ERC front panel | 0 | 0 | |
| DRC main | 0 violations, 0 unconnected | 21 parity warnings | 15 "Exclude from BOM differs" (FID1-3, H1-4, J1, J2, J6, J7, J8, J13, R811, R812) and 6 "DNP differs" (J1, J2, J6, J7, J8, J13). |
| DRC front panel | 0, 0 | 2 | LCSC field missing on J411 and J412. |

The project settings turn off several checks:
- **ERC:** global label used only once, four-way junctions, SPICE model, footprint filters.
- **DRC:** missing courtyard, track not centred on via, tuning profiles, footprint filters, component type vs pads.

The board is 4-layer (In1/In2 are "power" layers), routed (2634 segments), and has a single GND zone on all four layers.

Files written to `C:\Users\Liang\AppData\Local\Temp\claude\audit-electronics\`:
- `erc-main.json`, `erc-main.rpt`, `erc-front.json`, `erc-front.rpt`
- `drc-main.json`, `drc-main.rpt`, `drc-front.json`, `drc-front.rpt`
- `class-board.net` (KiCad format), `class-board.xml`, `front-panel.xml`

## 2. TX chain (sheet `/nmr_tx/`; generator `hardware/scripts/sheet_nmr_tx.py`)
- **DDS:** U801 AD9834BRUZ.
  - MCLK is the Si5351 CLK0 at 50 MHz through R703 33 Ω.
  - R801 6.8k sets 3.18 mA full scale. R802/R803 200 Ω loads give 0.636 Vpp. C807 20 pF.
  - FSYNC = GPIO41, PSELECT = GPIO42, SDATA/SCLK on the shared SPI bus.
  - **RESET and SLEEP only have 10k pull-downs (R817/R818) and are not driven by anything.** Firmware must reset the part through its control register.
- **Reconstruction filter:** 3rd-order Butterworth at 3 MHz: C808 390 pF, L801 15 µH, C809 130 pF. C810 1 µF couples into TX_IN.
- **Bias:** R820 47k from TX_VMID. The 2026-10-01 fix is in the netlist.
- **Power amp:** U802 OPA564AIDWPR on a single supply, +VEXT_TX through FB802; V− = GND.
  - Gain: R807 6.49k / R808 270 Ω gives G = 25 when header J10 1-2 is fitted. With no shunt, G = 1.
  - R808 returns to TX_VMID. C813 was removed, and R805/R806 are now 10k (they were 100k).
  - ISET: R809 11k, so I_LIM = 1.5 A.
  - E/S = TX_EN on GPIO40, with R810 10k pull-down.
  - **I_FLAG and T_FLAG are unconnected**: they end at the DNP pull-ups R811/R812. `pins.h:96-97` sets both to −1.
- **Output path:** TX_A goes to D801/D802 SS54 rail clamps, the R814 10 Ω + C817 10 nF snubber, then **R813 4.7 Ω 1 W** and **C818 10 µF**, into header J11. J11 1-2 gives full output; 2-3 selects the −20 dB pad (R815 910 Ω / R816 100 Ω). J11 pin 2 is net TX.
- **Route to the coil:** TX goes to link J6 pins 10/12, then panel J1 pins 10/12, then the TX SMA J20 and the **TX COIL terminal J32** pin 1 (pin 2 = GND).
- **Output limits:** design swing is 15.9 Vpp (±7.95 V) at +VEXT = 18 V. Current is limited to 1.5 A. At lower +VEXT (the input range goes down to 7 V) the stage will clip; I did not quantify where (VERIFY).

## 3. RX chain (sheet `/nmr_rx/`)
- **Input:** RX SMA (panel J13) goes to panel J1 pin 20, then main J6 pin 20, then net RX.
- **On the RX node:** crossed diodes D703/D704 1N4148W to GND, tank C710 1.2 nF + C711 100 pF + C712 22 pF (all fitted, 1.322 nF total), R711 1M to GND, then R710 100 Ω in series to the LNA input.
- **LNA stage 1:** U703A OPA1656 on ±12 V. R712 10k / R713 100 Ω gives G = 101; R714 1k is the alternative.
  - **Header J3: pin 1 = R712, pin 2 = LNA_FB1, pin 3 = R714. Without a shunt, stage 1 has no feedback.** See §7.
- **Blanking:** C720 10 nF and R721 10k (high-pass at 1.59 kHz) feed U704 DG419. S2 = signal and S1 = GND, so RX_BLANK low means blanked. RX_BLANK is GPIO8 with R724 10k pull-down.
- **LNA stage 2:** U703B, R722 9.1k / R723 1k gives G ≈ 10.1 via header J9 (no shunt gives G = 1). C721 100 pF.
- **Mixer:**
  - U705A unity-gain inverter (R901/R902 10k) makes S−.
  - C901-C904 10 nF couple the signal in. R906-R909 10k bias to V_MID = 1.65 V (R903/R904 divider, U705B buffer, R905 100 Ω). D905-D908 BAV99 clamp to 0 / +3V3A.
  - U901/U902 TS5A23157 form a double-balanced commutator.
  - The LO comes from Si5351 CLK1 (= 4 × f_LO) through R704/C706 into U702 74HC74, wired as a Johnson counter, giving LO_I and LO_Q. /CLR is on expander P1.4.
- **IF filtering and gain:**
  - Passive RC: R910-R913 1k with C910-C913 10 nF to V_MID, pole at 15.9 kHz.
  - Difference amplifiers U706 OPA1612: R914/R916/R918/R923 1k, R915/R917/R919/R924 20k, C914/C915 560 pF (pole 14.2 kHz). Outputs are COND_OUT1/COND_OUT2.
- **ADC channels:** COND_OUT1 goes through header J14 2-3, then R117 1k / C117 1 nF / D117 BAV99 to ±12 V, into ADS8688 **AIN_3P (pin 23, chip channel 3)**. COND_OUT2 goes through J15 and R118 into **AIN_2P (chip channel 2)**. This matches `pins.h:32` (kAinOfAi). The docs' "ch 7/8" refers to panel numbering AI7/AI8.
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

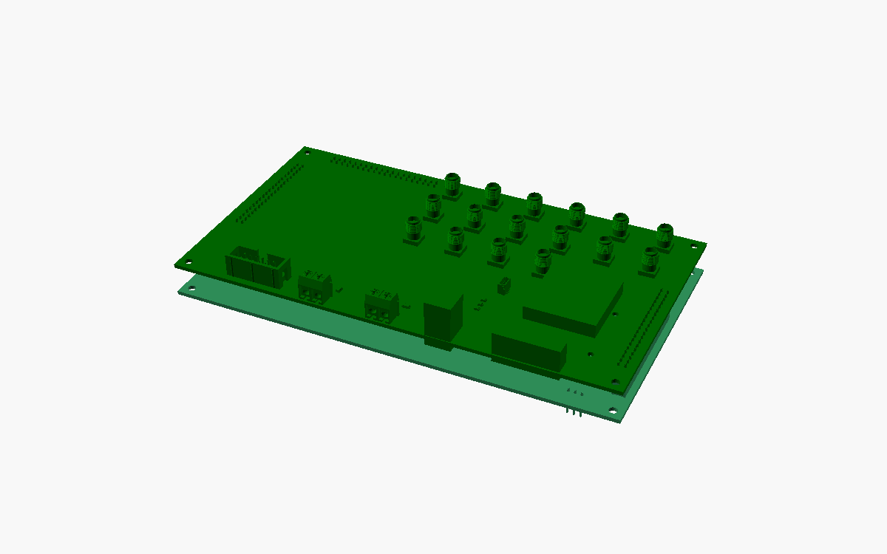
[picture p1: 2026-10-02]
mechanical/img/boards.png

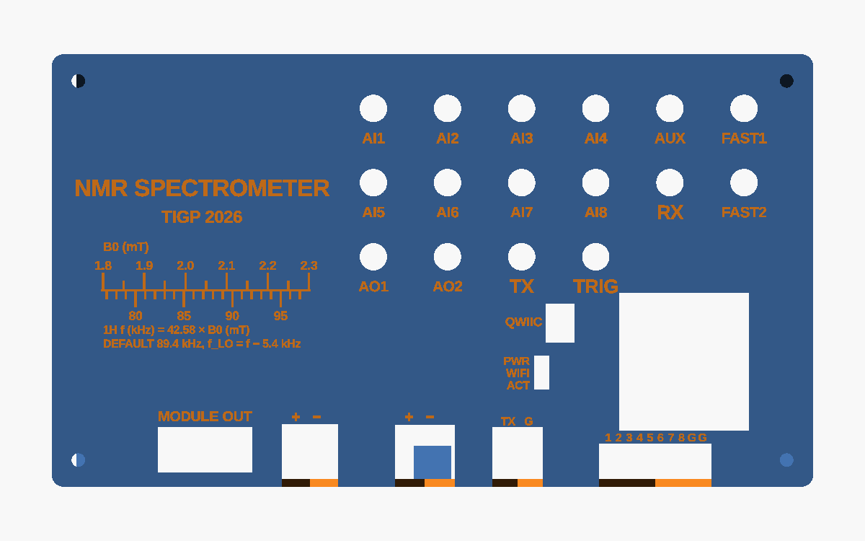
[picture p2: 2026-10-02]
mechanical/img/cover.png

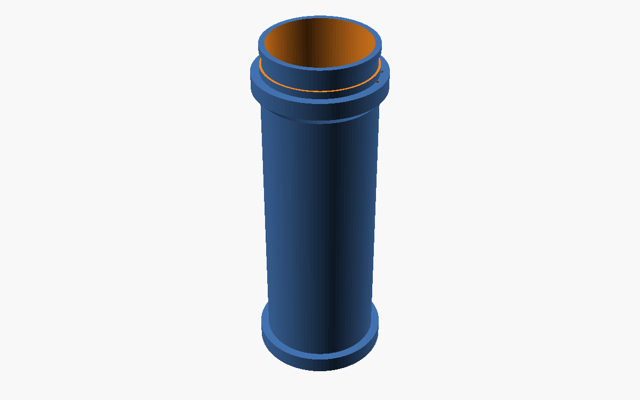
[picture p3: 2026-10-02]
mechanical/img/former.png

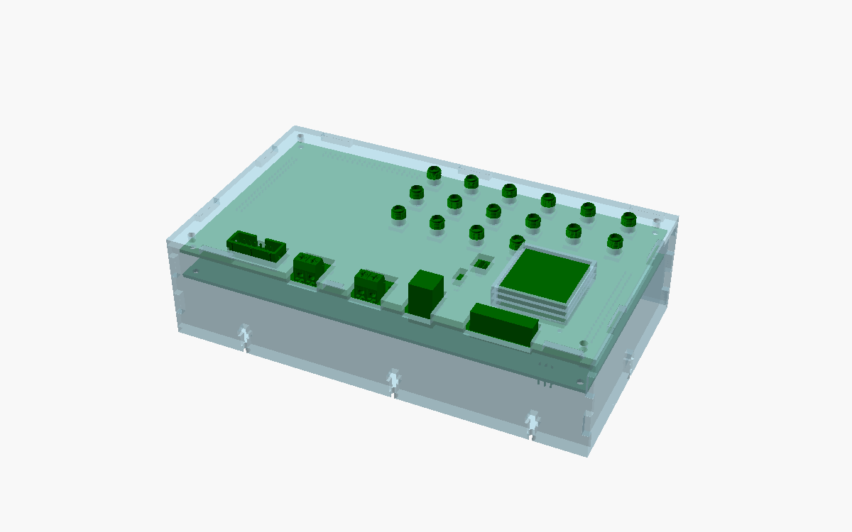
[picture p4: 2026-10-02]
mechanical/img/cut-box.png

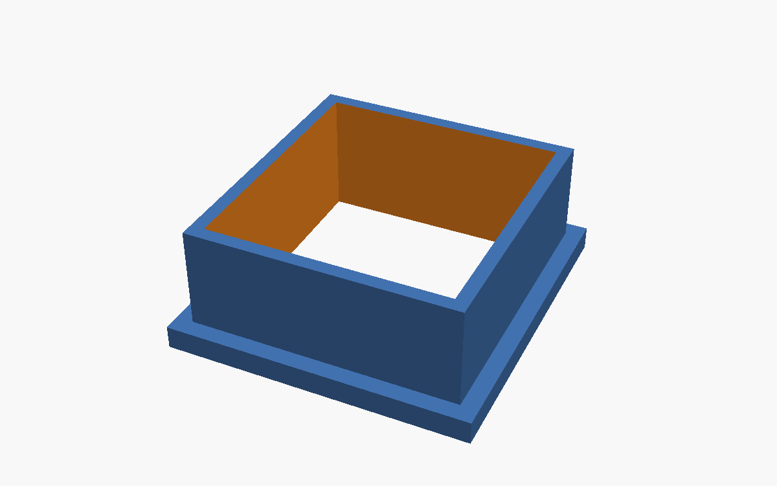
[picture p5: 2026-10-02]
mechanical/img/hood.png

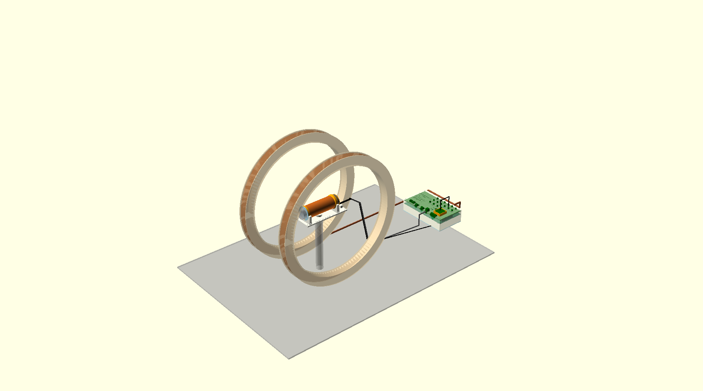
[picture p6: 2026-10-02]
mechanical/instrument.png

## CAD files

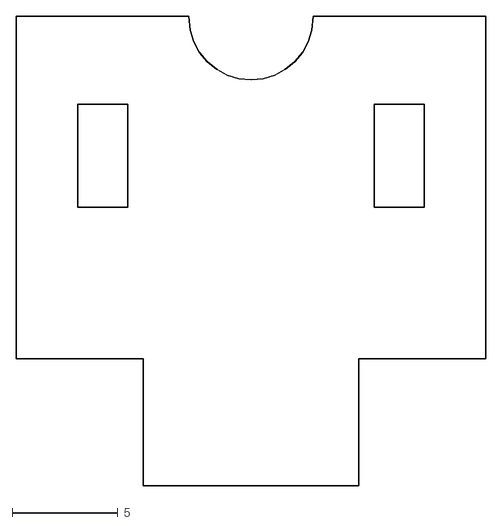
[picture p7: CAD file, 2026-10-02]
fabrication/laser/cut-probe__cradle_anchor.cut.dxf
22.1 x 22.1

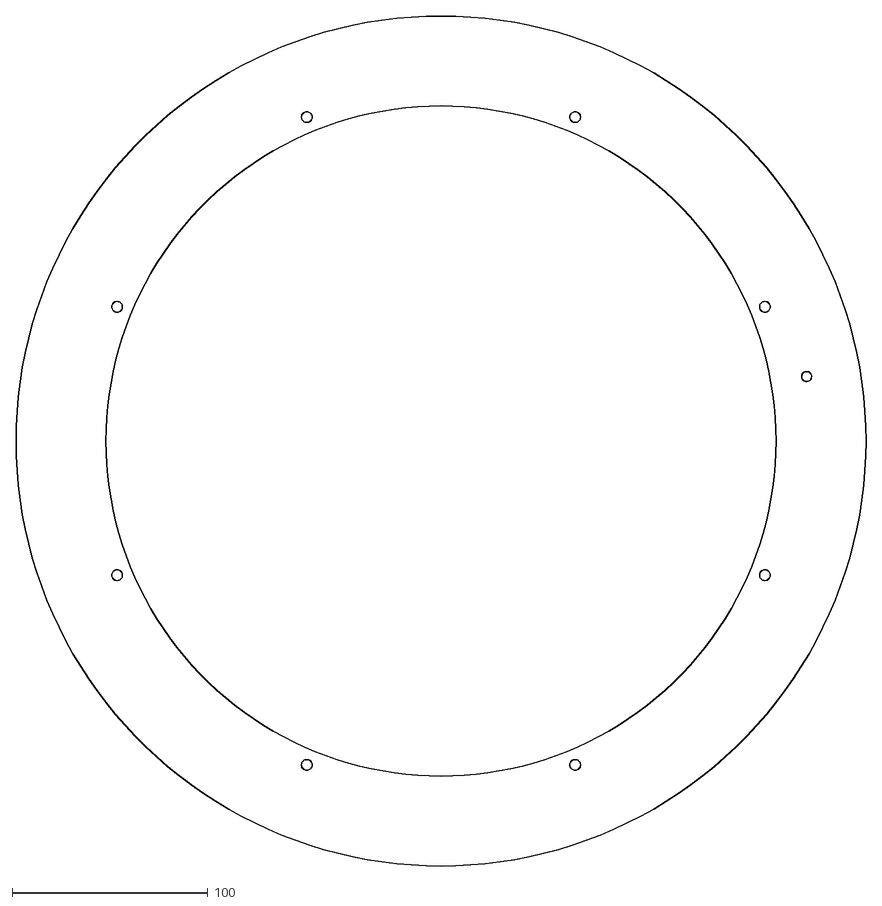
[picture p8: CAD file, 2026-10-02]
fabrication/water-jet/cut-probe__b0_flange_lead.cut.dxf
433.9 x 433.9

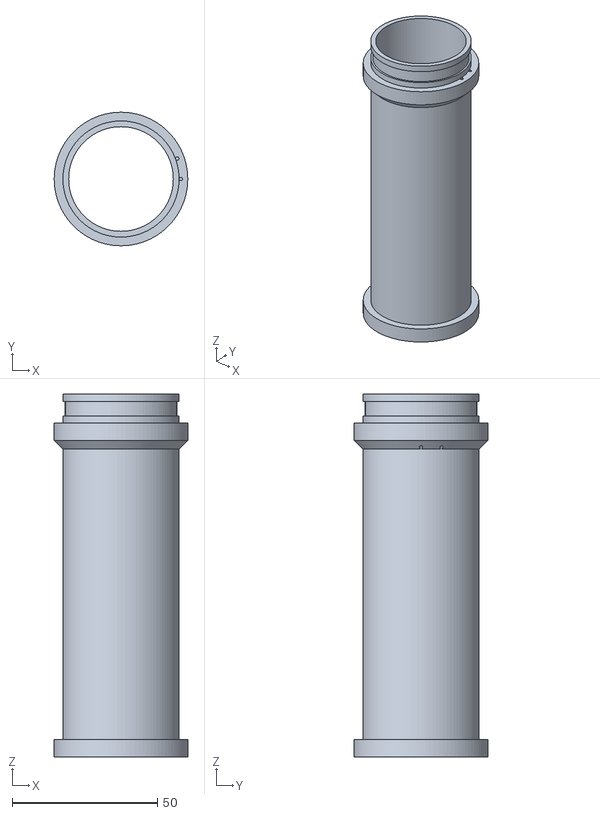
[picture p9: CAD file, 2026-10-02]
mechanical/probe-former.stl
46.0 x 46.0 x 125.0

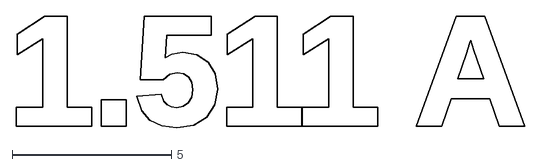
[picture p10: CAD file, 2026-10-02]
fabrication/laser/cut-spectrum__fin6.engrave.dxf
16.0 x 3.49

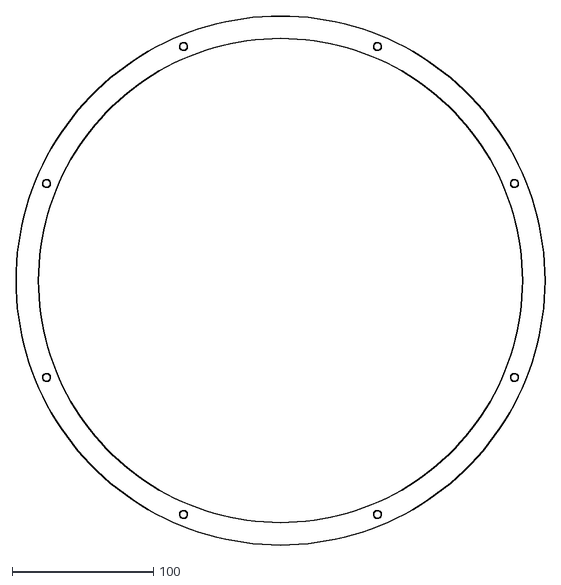
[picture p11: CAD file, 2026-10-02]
fabrication/water-jet/cut-probe__b0_spacer.cut.dxf
373.9 x 373.9

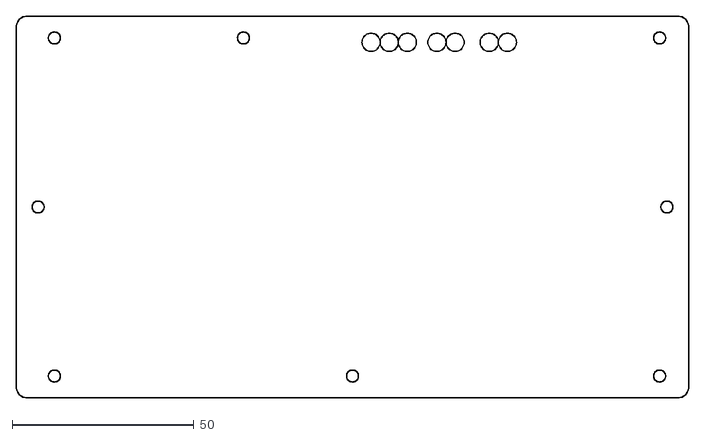
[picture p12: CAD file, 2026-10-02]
mechanical/bottom-plate.dxf
185.0 x 105.0

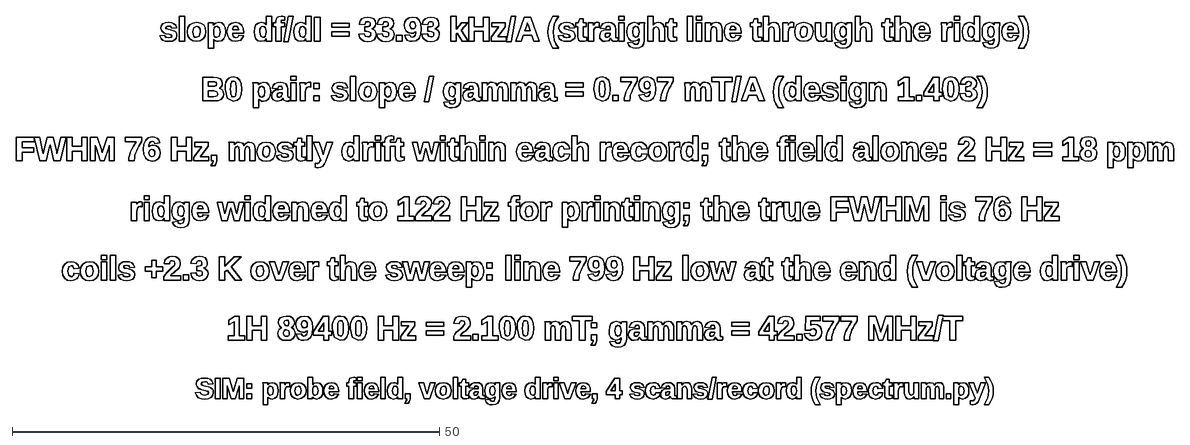
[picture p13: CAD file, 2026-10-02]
fabrication/laser/cut-spectrum__card.engrave.dxf
135.5 x 45.5

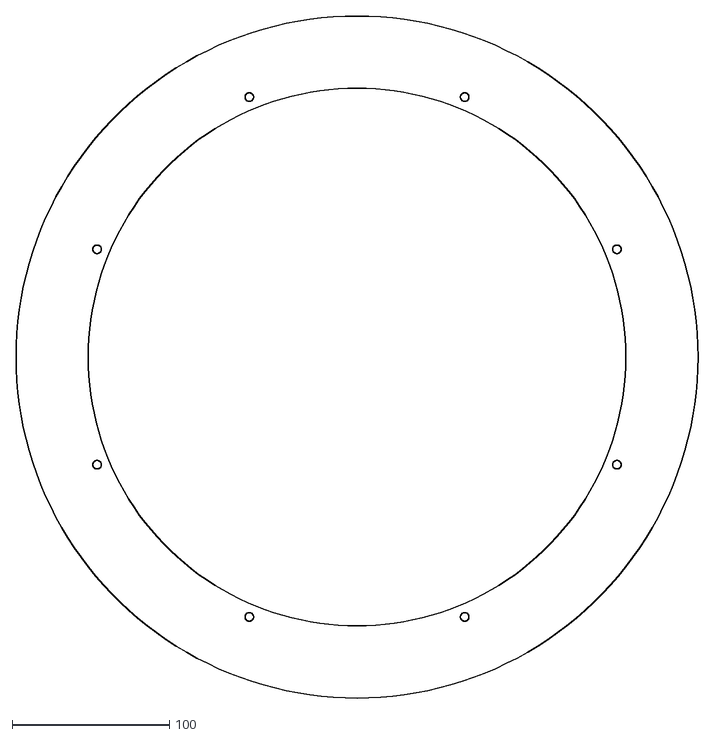
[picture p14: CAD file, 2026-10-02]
fabrication/water-jet/cut-probe__b0_flange.cut.dxf
433.9 x 433.9

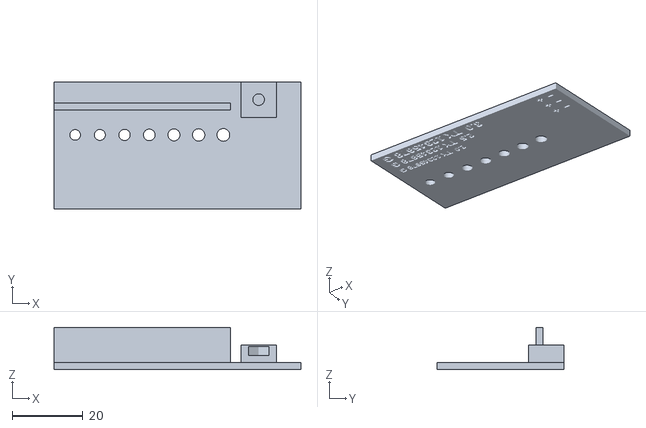
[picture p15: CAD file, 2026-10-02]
mechanical/coupon.stl
70.0 x 36.0 x 12.0

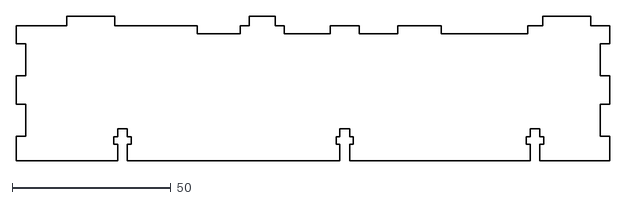
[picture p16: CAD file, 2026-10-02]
fabrication/laser/cut-housing__front.cut.dxf
187.1 x 45.4

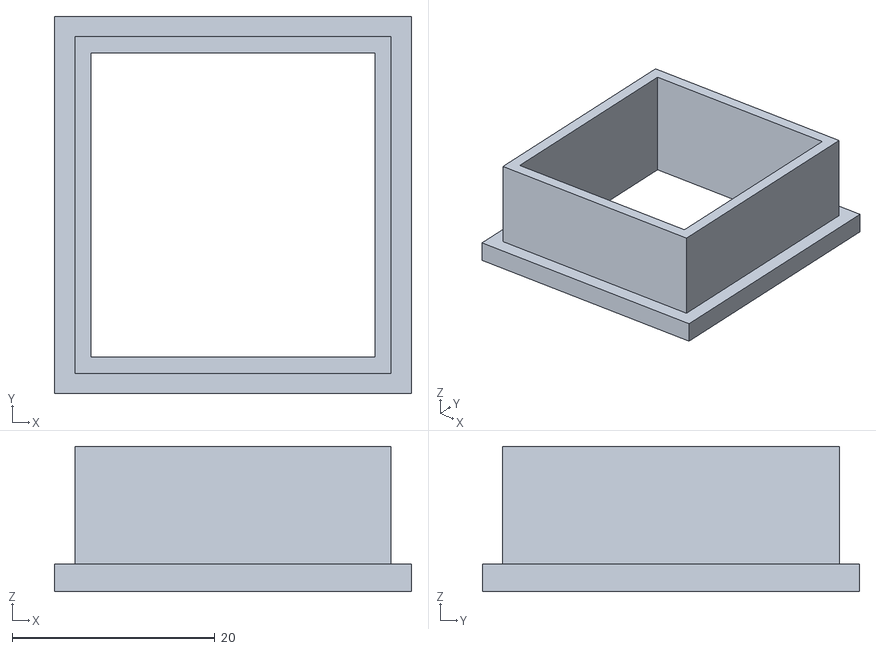
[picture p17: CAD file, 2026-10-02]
mechanical/hood.stl
35.2 x 37.2 x 14.3

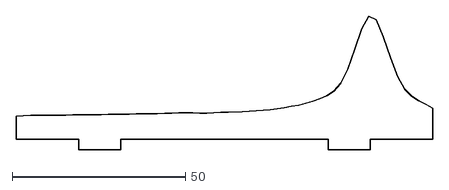
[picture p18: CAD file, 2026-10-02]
fabrication/laser/cut-spectrum__fin7.cut.dxf
120.1 x 38.5

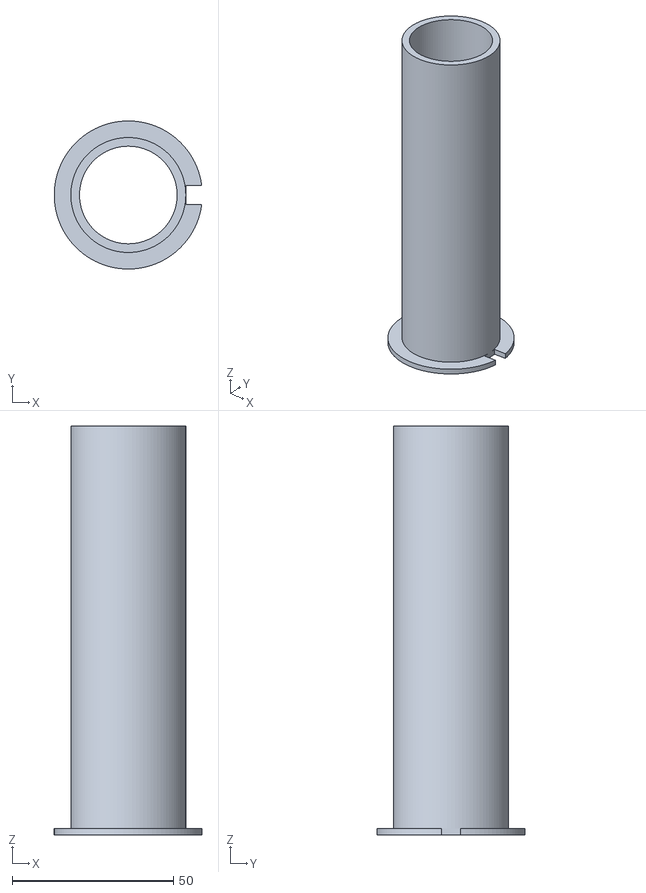
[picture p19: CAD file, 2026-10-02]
mechanical/probe-sleeve.stl
45.8 x 46.0 x 127.0

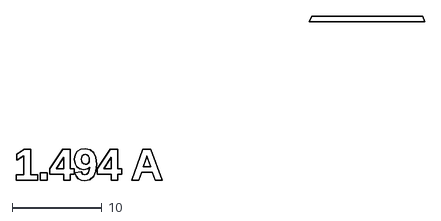
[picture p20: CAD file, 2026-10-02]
fabrication/laser/cut-spectrum__fin2.engrave.dxf
45.4 x 18.3

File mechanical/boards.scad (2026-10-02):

// The two boards in KiCad's frame (y points down: the boards lie at x 0..180, y -115..-15).
// stacked = true : assembled as in the housing, front panel face up, main board under it -
//                  housing.scad's own boards(), so the stack here can never drift from the one
//                  the housing is built round (the gap, the turn-over, the dev board).
// stacked = false: side by side, each board as exported.
use <housing.scad>

stacked = true;

if (stacked) {
    boards();
} else {
    // class-board-2026 cloned beside this repository (see housing.scad, board_dir)
    import("../../class-board-2026/hardware/release/front-panel.stl");
    translate([200, 0, 0]) import("../../class-board-2026/hardware/release/class-board.stl");
}

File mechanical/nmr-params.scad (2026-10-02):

// The NMR numbers every model in this folder shares, in one place, with where each comes from.
// Included by housing.scad (the B0/f scale on the cover), probe.scad (the B0 pair) and
// instrument.scad (the checks across the whole setup). Change a default here, not in a model.

// firmware / host defaults (host/instrument.py NMR_DEFAULTS, firmware/NMR-FIRMWARE.md)
nmr_f_tx  = 89400;               // Hz, transmit = expected proton line
nmr_f_lo  = 84000;               // Hz, local oscillator
nmr_if    = nmr_f_tx - nmr_f_lo; // Hz, 5.4 kHz IF
nmr_gamma = 42.577e6;            // Hz/T, 1H gyromagnetic ratio / 2 pi
nmr_B0    = nmr_f_tx / nmr_gamma;   // T, 2.1 mT

// the class coil (workbook blocks/a.md, b.md; sheet_nmr_rx.py)
coil_L    = 2.53e-3;             // H
coil_R    = 6.7;                 // ohm DC
coil_Q    = 10;
tank_C    = 1 / (pow(2 * PI * nmr_f_tx, 2) * coil_L);   // F, about 1.25 nF
tank_fit  = [1.2e-9, 100e-12, 22e-12];                  // C710, C711, C712 on the board

// the board's limits on what drives the coils (design-decisions D-35, D-42; bring-up T-17, T-21)
vext_max  = 18;                  // V, +VEXT
hb_trip   = 2.0;                 // A, DRV8871 I_TRIP (B0 coil on J903 "H-BRIDGE")
tx_vpk    = 7.95;                // V, OPA564 output into the coil
rx_clamp  = 0.7;                 // V, D703/D704 crossed diodes at the RX SMA

// the acquisition (firmware/NMR-FIRMWARE.md settings defaults): what a record can contain
nmr_t90_us       = 417;          // us, 90 deg pulse
nmr_t_acq_start  = 1200e-6;      // s, end of the pulse to the first sample (dead time + margin)
nmr_t_acq        = 2.0;          // s, record length
nmr_rate         = 25000;        // S/s, decimated complex rate (100 kS/s / decim 4)
nmr_t_repeat     = 3.0;          // s, between scans

// the sample and the room (spectrum.py's simulator and instrument.scad's drift check)
water_T2   = 2.0;                // s, intrinsic T2 of tap water at low field (the line in a perfect field)
water_T1   = 2.5;                // s
cu_alpha   = 0.00393;            // 1/K, copper resistance tempco: a voltage-driven coil loses current as it warms
cu_c       = 385;                // J/(kg K), copper heat capacity

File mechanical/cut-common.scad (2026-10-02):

// Shared by the cut-*.scad files: the machines, the cut width (kerf), what each file exports, and
// the joints every flat part uses. Change the machine or the sheet here, not in a part.
//
// layer = "cut"          the outlines to cut through, kerf-compensated (export DXF/SVG)
//         "engrave"      raster-engrave on the face that is up when cutting (labels, scales)
//         "engrave_back" raster-engrave on the other face: cut "cut", flip, align, engrave this
//         "preview"      everything, coloured, with the sheet outline (look, do not export)
// export_cut.py runs every part through every layer it has, into ../fabrication/.

layer = "preview";

// ---------------------------------------------------------------- machines (defaults; check yours)
// CO2 laser: 600 x 400 bed, 0.15 mm kerf in 3-6 mm acrylic. Never PVC (chlorine gas) or
// polycarbonate (chars, burns) or ABS (most makerspaces ban it) in a laser.
// Water-jet: a cutting service; 0.9 mm kerf, slight taper, no engraving, no hole smaller than
// about the sheet thickness, small parts need tabs - send one DXF per part, in mm.
laser_bed    = [600, 400];
laser_kerf   = 0.15;
jet_bed      = [1500, 3000];
jet_kerf     = 0.9;
jet_min_hole = 6;              // for 6 mm polycarbonate

// ---------------------------------------------------------------- sheet stock
t3 = 3;                        // acrylic (PMMA), laser
t6 = 6;                        // acrylic (PMMA), laser; or polycarbonate / HDPE for the water-jet
cut_fit = 0.2;                 // slot = tab + this (after kerf compensation)

// ---------------------------------------------------------------- layer plumbing
// kerf compensation: the beam removes kerf/2 either side of the line, so offsetting the whole
// part by +kerf/2 makes outlines larger and holes smaller by exactly what the cut takes away
module kerfed(k) offset(delta = k / 2) children();
module as_cut(k = laser_kerf) {
    if (layer == "cut") kerfed(k) children();
    if (layer == "preview") color("lightsteelblue") linear_extrude(1) children();
}
module as_engrave() {
    if (layer == "engrave") children();
    if (layer == "preview") color("darkred") translate([0, 0, 1]) linear_extrude(0.3) children();
}
module as_engrave_back() {
    if (layer == "engrave_back") mirror([1, 0]) children();     // seen from the back, as the laser sees it after the flip
    if (layer == "preview") color("orange") translate([0, 0, -0.3]) linear_extrude(0.3) children();
}
module sheet(size) if (layer == "preview") %translate([0, 0, -2]) cube([size[0], size[1], 1]);

// ---------------------------------------------------------------- joints
// tabs along the x axis from x0, height t, centred on the given positions
module tabs(xs, w, t) for (x = xs) translate([x - w / 2, 0]) square([w, t]);
// the matching slots, a hair bigger
module slots(xs, w, t) for (x = xs) translate([x - (w + cut_fit) / 2, -(t + cut_fit) / 2]) square([w + cut_fit, t + cut_fit]);
// M3 T-slot from an edge (the edge is y = 0, the slot goes in along +y): screw shank, then a
// cross slot for the nut, which lies flat in the sheet's plane
m3_shank = 3.2;  m3_nut_af = 5.6;  m3_nut_t = 2.5;  tslot_len = 10;  tslot_nut_at = 5;
module tslot() {
    translate([-m3_shank / 2, -1]) square([m3_shank, tslot_len + 1]);
    translate([-m3_nut_af / 2, tslot_nut_at]) square([m3_nut_af, m3_nut_t]);
}
// a ring, optionally only one segment of it (a, a + span degrees)
module ring2d(r0, r1, a = 0, span = 360, fn = 180) {
    if (span >= 360) difference() { circle(r = r1, $fn = fn); circle(r = r0, $fn = fn); }
    else intersection() {
        difference() { circle(r = r1, $fn = fn); circle(r = r0, $fn = fn); }
        polygon(concat([[0, 0]], [for (k = [0:16]) 2 * r1 * [cos(a + span * k / 16), sin(a + span * k / 16)]]));
    }
}

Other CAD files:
mechanical/spectrum.stl
fabrication/laser/cut-probe__b0_rail.cut.dxf
mechanical/probe-cradle.stl
fabrication/laser/cut-spectrum__fin6.cut.dxf
mechanical/cut-housing.scad
fabrication/laser/cut-housing__cover.cut.dxf
fabrication/laser/cut-housing__cover.engrave.dxf
fabrication/laser/cut-housing__cover.engrave_back.dxf
fabrication/laser/cut-housing__front.engrave.dxf
fabrication/laser/cut-housing__hood_frame.cut.dxf
fabrication/laser/cut-housing__plate.cut.dxf
fabrication/laser/cut-housing__rear.cut.dxf
fabrication/laser/cut-housing__rear.engrave.dxf
fabrication/laser/cut-housing__side.cut.dxf
fabrication/laser/cut-housing__washer.cut.dxf
fabrication/laser/cut-probe__b0_brace.cut.dxf
fabrication/laser/cut-probe__cheek.cut.dxf
fabrication/laser/cut-probe__cheek.engrave.dxf
fabrication/laser/cut-probe__cheek_lead.cut.dxf
fabrication/laser/cut-probe__cheek_lead.engrave.dxf
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

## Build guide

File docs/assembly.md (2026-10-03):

# Assembly order & bill of materials

How to build the instrument from the fabrication files, in order. The detailed parts list (every laser/water-jet piece,
with material, quantity and file) is generated into [`../fabrication/CUT-LIST.md`](../fabrication/CUT-LIST.md) by
`legacy/mechanical/export_cut.py`; the printed parts come from `legacy/mechanical/*.scad` via OpenSCAD. Design rationale
and the 60 mm active-region decision are in [`design-closure.md`](design-closure.md). Frame: **+x** coil/sample axis,
**+y** B0 (Helmholtz) axis, **+z** up.

> Design stage — nothing here has been built or measured. No steel anywhere near the sample or coil (use brass/nylon
> fasteners), and check every cable and plug with a phone magnetometer before it goes near the probe.

## Bill of materials (summary)

**Printed (PLA/PETG)** — `OpenSCAD -o <part>.stl -D 'part="…"' probe.scad`:
- `former` ×1 (85 mm, 266-turn / 60 mm winding), `sleeve` ×1, `cradle` ×1. Housing shell + hood if printing the housing.

**Laser-cut (3 / 6 mm acrylic)** and **water-jet (6 mm polycarbonate, B0 rings)** — see `fabrication/CUT-LIST.md`:
- Probe: cheeks ×4 (2 plain + 2 lead), sleeve flange, cradle base/saddles/anchor/nut-plate.
- Magnet: B0 ring flanges + spacers (water-jet), B0 rails ×2 + braces ×2, baseplate.
- Housing: cover/walls or printed shell, bottom plate, OLED hood frames, spectrum card.

**Bought:**
- Former tube 40×2 mm (~95 mm), sleeve tube 35×2 mm (~95 mm), 50 mL centrifuge tube (the sample).
- Class coil: AWG26 enamelled, **~45 m** (34 m needed for 266 turns). B0 pair: AWG16, **784 m (~9.2 kg)**.
- Nylon M4/M6 threaded rod + nuts (B0 ring stacks, 8/coil), M3 brass/nylon screws (cradle, housing), **brass ¼"-20 nut**
  (tripod), M3×12 ×4 + M3×10 + nut ×8 (housing). Solvent cement for acrylic. Two-core screened cable (probe), RG174 (RX).

## Assembly order

1. **Probe.** Glue the two cheeks (2× 3 mm laser pieces each) onto the former tube at 0–6 mm and the lead-end position.
   Wind **266 turns AWG26 in two layers** over the 60 mm length (start lead out through the lead cheek, tensioned, a drop
   of cyanoacrylate on the first turns; both leads leave at the stub). Cable-tie the leads + cable to the stub.
2. **Sample fit.** Push the sleeve into the former bore; the sleeve flange seats against the plain cheek. The 50 mL tube
   goes in cap-first until the **cap stops at the flange** — this is the axial datum that returns the sample to the
   active ROI every time (the winding z 6–66 is covered by the sample; the tube overhangs 16 mm, which is fine).
3. **Cradle.** Assemble the laser cradle (base + two saddles + anchor + nut-plate), press the **brass ¼"-20 tripod nut**
   into the nut-plate. The base is engraved **"AXIS 90° TO B0 | EARTH FIELD: E–W"** and marks the winding centre.
4. **Magnet.** For each coil, stack flange + spacers + flange on 8 nylon rods and wind **312 turns AWG16**. Seat both
   ring stacks in the two **rails** (notches fix the 200 mm Helmholtz spacing) and tie the rails with the **braces**.
5. **Base/frame.** Fix the two rails to the **baseplate**; mount the probe cradle (on its tripod) to the baseplate so the
   sample ROI sits at the magnetic centre (x = y = 0). This ties magnet + probe to one reference (verified clear: probe
   fits the ring aperture, rings clear the plate by 10 mm — `cut-probe.scad` clearance echo).
6. **Electronics.** Mount the board stack in the housing (M3 standoffs from the cover; bottom plate on the nut-pocket
   bosses; feet underneath). Place the housing **≈450 mm from the sample** (RF/magnet isolation; nearest steel then
   ≥300 mm) with its TX-COIL edge facing the probe.
7. **Cables.** Route TX (two-core → TX COIL terminal), RX (RG174 → RX SMA on the cover), B0 (AWG18 pair → H-BRIDGE). Keep
   RF leads short; zip-tie the probe end to the stub anchor and the housing end to the **strain-relief bar** so a pull
   reaches the bar, not J32 / the OPA564 output or the SMA.

Then follow the **commissioning sequence** (mechanical → B0 → RF → NMR → shim) and **acceptance criteria** in
[`design-closure.md`](design-closure.md). Bench-only steps that remain: tune/match the tank, **recalibrate t90 by
nutation** (the 369 µs value is a calculation), map B0 over the ROI vs the simulation, acquire the first FID, and decide
on shimming from the measured linewidth. Note the open board-side blocker: **TX and RX on one coil** trips the OPA564 on
the first pulse (needs a series TX diode pair + RX series element, or a separate receive coil) before a real scan.

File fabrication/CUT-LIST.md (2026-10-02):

# Cut list

Generated by `py export_cut.py` from cut-probe.scad, cut-housing.scad and
cut-spectrum.scad - do not edit; change the .scad files (machine and sheet settings: cut-common.scad) and re-run.

## Before cutting

- **Laser** (CO2, kerf 0.15 mm compensated in the files): acrylic only. Never PVC (chlorine gas), polycarbonate
  (burns) or ABS. Load the `.engrave` file as a raster/fill layer and the `.cut` file as a vector cut, engrave
  first, cut last. `.engrave_back`: cut the part, flip it about its vertical axis in the bed, align, engrave
  (the file is already mirrored) - 1.2 mm deep for the housing cover's optocoupler pockets.
- **Water-jet** (kerf 0.9 mm compensated): send the `.cut.dxf` files, mm, one part per file, with the quantity
  below. No hole is below 6 mm. Ask for no taper compensation; the faces only need to be flat.
- **Cut the test first:** one `cradle_saddle` and one housing `washer` - check the slot fit and the M3 holes on
  your machine; change `laser_kerf` / `cut_fit` in cut-common.scad if they are loose or tight.

## Parts

| File | Piece | Qty | Material | Machine | Files |
|---|---|---|---|---|---|
| cut-probe | cheek | 2 | 3 mm acrylic | laser | `cut-probe__cheek.cut.svg`<br>`cut-probe__cheek.cut.dxf`<br>`cut-probe__cheek.engrave.svg`<br>`cut-probe__cheek.engrave.dxf` |
| cut-probe | cheek_lead | 2 | 3 mm acrylic | laser | `cut-probe__cheek_lead.cut.svg`<br>`cut-probe__cheek_lead.cut.dxf`<br>`cut-probe__cheek_lead.engrave.svg`<br>`cut-probe__cheek_lead.engrave.dxf` |
| cut-probe | sleeve_flange | 1 | 3 mm acrylic | laser | `cut-probe__sleeve_flange.cut.svg`<br>`cut-probe__sleeve_flange.cut.dxf` |
| cut-probe | cradle_base | 1 | 6 mm acrylic | laser | `cut-probe__cradle_base.cut.svg`<br>`cut-probe__cradle_base.cut.dxf`<br>`cut-probe__cradle_base.engrave.svg`<br>`cut-probe__cradle_base.engrave.dxf` |
| cut-probe | cradle_saddle | 2 | 6 mm acrylic | laser | `cut-probe__cradle_saddle.cut.svg`<br>`cut-probe__cradle_saddle.cut.dxf` |
| cut-probe | cradle_anchor | 1 | 6 mm acrylic | laser | `cut-probe__cradle_anchor.cut.svg`<br>`cut-probe__cradle_anchor.cut.dxf` |
| cut-probe | cradle_nutplate | 1 | 6 mm acrylic | laser | `cut-probe__cradle_nutplate.cut.svg`<br>`cut-probe__cradle_nutplate.cut.dxf` |
| cut-probe | b0_flange | 3 | 6 mm polycarbonate | water-jet | `cut-probe__b0_flange.cut.dxf` |
| cut-probe | b0_flange_lead | 1 | 6 mm polycarbonate | water-jet | `cut-probe__b0_flange_lead.cut.dxf` |
| cut-probe | b0_spacer | 10 | 6 mm polycarbonate | water-jet | `cut-probe__b0_spacer.cut.dxf` |
| cut-probe | b0_rail | 2 | 6 mm acrylic | laser | `cut-probe__b0_rail.cut.svg`<br>`cut-probe__b0_rail.cut.dxf` |
| cut-probe | b0_brace | 2 | 6 mm acrylic | laser | `cut-probe__b0_brace.cut.svg`<br>`cut-probe__b0_brace.cut.dxf` |
| cut-housing | cover | 1 | 3 mm acrylic | laser | `cut-housing__cover.cut.svg`<br>`cut-housing__cover.cut.dxf`<br>`cut-housing__cover.engrave.svg`<br>`cut-housing__cover.engrave.dxf`<br>`cut-housing__cover.engrave_back.svg`<br>`cut-housing__cover.engrave_back.dxf` |
| cut-housing | front | 1 | 3 mm acrylic | laser | `cut-housing__front.cut.svg`<br>`cut-housing__front.cut.dxf`<br>`cut-housing__front.engrave.svg`<br>`cut-housing__front.engrave.dxf` |
| cut-housing | rear | 1 | 3 mm acrylic | laser | `cut-housing__rear.cut.svg`<br>`cut-housing__rear.cut.dxf`<br>`cut-housing__rear.engrave.svg`<br>`cut-housing__rear.engrave.dxf` |
| cut-housing | side | 2 | 3 mm acrylic | laser | `cut-housing__side.cut.svg`<br>`cut-housing__side.cut.dxf` |
| cut-housing | plate | 1 | 3 mm acrylic | laser | `cut-housing__plate.cut.svg`<br>`cut-housing__plate.cut.dxf` |
| cut-housing | hood_frame | 3 | 3 mm acrylic | laser | `cut-housing__hood_frame.cut.svg`<br>`cut-housing__hood_frame.cut.dxf` |
| cut-housing | washer | 4 | 3 mm acrylic | laser | `cut-housing__washer.cut.svg`<br>`cut-housing__washer.cut.dxf` |
| cut-spectrum | fin0 (1.485 A) | 1 | 3 mm acrylic | laser | `cut-spectrum__fin0.cut.svg`<br>`cut-spectrum__fin0.cut.dxf`<br>`cut-spectrum__fin0.engrave.svg`<br>`cut-spectrum__fin0.engrave.dxf` |
| cut-spectrum | fin1 (1.489 A) | 1 | 3 mm acrylic | laser | `cut-spectrum__fin1.cut.svg`<br>`cut-spectrum__fin1.cut.dxf`<br>`cut-spectrum__fin1.engrave.svg`<br>`cut-spectrum__fin1.engrave.dxf` |
| cut-spectrum | fin2 (1.494 A) | 1 | 3 mm acrylic | laser | `cut-spectrum__fin2.cut.svg`<br>`cut-spectrum__fin2.cut.dxf`<br>`cut-spectrum__fin2.engrave.svg`<br>`cut-spectrum__fin2.engrave.dxf` |
| cut-spectrum | fin3 (1.498 A) | 1 | 3 mm acrylic | laser | `cut-spectrum__fin3.cut.svg`<br>`cut-spectrum__fin3.cut.dxf`<br>`cut-spectrum__fin3.engrave.svg`<br>`cut-spectrum__fin3.engrave.dxf` |
| cut-spectrum | fin4 (1.502 A) | 1 | 3 mm acrylic | laser | `cut-spectrum__fin4.cut.svg`<br>`cut-spectrum__fin4.cut.dxf`<br>`cut-spectrum__fin4.engrave.svg`<br>`cut-spectrum__fin4.engrave.dxf` |
| cut-spectrum | fin5 (1.506 A) | 1 | 3 mm acrylic | laser | `cut-spectrum__fin5.cut.svg`<br>`cut-spectrum__fin5.cut.dxf`<br>`cut-spectrum__fin5.engrave.svg`<br>`cut-spectrum__fin5.engrave.dxf` |
| cut-spectrum | fin6 (1.511 A) | 1 | 3 mm acrylic | laser | `cut-spectrum__fin6.cut.svg`<br>`cut-spectrum__fin6.cut.dxf`<br>`cut-spectrum__fin6.engrave.svg`<br>`cut-spectrum__fin6.engrave.dxf` |
| cut-spectrum | fin7 (1.515 A) | 1 | 3 mm acrylic | laser | `cut-spectrum__fin7.cut.svg`<br>`cut-spectrum__fin7.cut.dxf`<br>`cut-spectrum__fin7.engrave.svg`<br>`cut-spectrum__fin7.engrave.dxf` |
| cut-spectrum | plate | 1 | 3 mm acrylic | laser | `cut-spectrum__plate.cut.svg`<br>`cut-spectrum__plate.cut.dxf`<br>`cut-spectrum__plate.engrave.svg`<br>`cut-spectrum__plate.engrave.dxf` |
| cut-spectrum | card (answers) | 1 | 3 mm acrylic | laser | `cut-spectrum__card.cut.svg`<br>`cut-spectrum__card.cut.dxf`<br>`cut-spectrum__card.engrave.svg`<br>`cut-spectrum__card.engrave.dxf` |

## Bought, not cut

- Former: acrylic or PVC tube 40 x 2 mm, 125 mm long (cut by saw, not laser). Sleeve: acrylic tube 35 x 2 mm, 125 mm.
- Coil: AWG26 enamelled wire, 60 m (51 m needed). B0 pair: AWG16, 2 x 392 m (784 m, about 9.2 kg).
- Nylon: M4 or M6 threaded rod + nuts for the B0 stacks (8 per coil, M6 for the water-jet rings), M3 screws for the cradle.
- Brass 1/4"-20 nut (tripod). Housing: M3x12 x 4 (top), M3x10 + M3 nut x 8 (plate). Solvent cement for acrylic.

## Checks (from the .scad files)

**cut-probe**

- cheeks: 50 mm, bore 40.2, lead holes at r 21.8 (2.6 mm of acrylic outside them); glue 2 + 2 on the tube at 0..6 and 109..115 mm
- cradle: base [157, 70.4] x 6, saddles 66.4 x 33.2 mm, coil axis 39.2 mm above its underside
- B0 coil: 5 spacers + 2 flanges = 42 mm stack, channel 30 x 27 mm for 28 x 27; rings r 171.5..216.5 mm, 1 piece (water-jet), segment fits the laser bed: true
- B0 rails: 362 x 54.4785 mm, notches 200 mm apart (Helmholtz spacing = R), rings 10 mm off the table

**cut-housing**

- box 187 x 107 x 48.3 mm; walls 42.3 mm + 3 mm tabs; cover top 7.6 -> SMA thread above it 3.8 mm
- board to wall: x 0.5 / 0.5, y 0.5 / 0.5 mm
- OLED hood: 3 frames on the cover, top 16.6 vs module top 15.42
- screws: M3x12 from the top (cover 3 + washer 3 + panel 1.6 = 7.6, 4.4 into the stand-off); M3x10 + nut, 8 pcs, for the plate
- sheet: everything on one 600 x 400 sheet of 3 mm acrylic

**cut-spectrum**

- spectrum fins (laser, 3 mm acrylic, kerf 0.15): 8 fins at rows [0, 4, 8, 12, 16, 20, 24, 28], 8.4 mm clear between fins; slots 3.2 mm; plate 146 x 104 mm

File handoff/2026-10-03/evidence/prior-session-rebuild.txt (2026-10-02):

HISTORICAL SESSION EVIDENCE; NOT AN EXECUTABLE SCRIPT OR VERIFIED WORKING TREE
Source: Pasted text.txt; SHA-256: c4f56a1a92747fb1d7b77dd57802df4431ef472958be1cf2dc8c7db71106579d
Original physical lines 3883-10746, with original line labels.
Commands/claims are historical. Later edits may supersede earlier writes. No reported NMR builds/tests/measurements were rerun during handoff preparation. The unrelated article and lab inventory are intentionally excluded.

L3883: This is a large rebuild, so I'll work through it in your milestones and report a checkpoint after each. First I need to find the two archives and see which toolchains this machine actually has. That decides what I can build and measure here, and what stays a hardware-gated step.
L3884: 
L3885: 
L3886: 
L3887: Bash Find the archives and check available toolchains
L3888: IN
L3889: cd /c/Users/Liang && find . -maxdepth 3 \( -name "class-board-2026*.zip" -o -name "nmr-instrument*.zip" \) -not -path "./AppData/*" 2>/dev/null; for t in g++ clang++ cl cmake ninja make emcc node npm pio idf.py kicad-cli wolframscript openscad; do printf "%-14s %s\n" $t "$(command -v $t || echo -)"; done; ls "/c/Program Files/KiCad" 2>/dev/null; ls ~/.platformio/packages 2>/dev/null | head -20; ls "/c/Program Files/Wolfram Research" 2>/dev/null
L3890: 
L3891: OUT
L3892: ./tigp-2026/class-board-2026 (2).zip
L3893: ./tigp-2026/nmr-instrument.zip
L3894: g++            /c/mingw64/bin/g++
L3895: clang++        /c/mingw64/bin/clang++
L3896: cl             -
L3897: cmake          /c/mingw64/bin/cmake
L3898: ninja          /c/mingw64/bin/ninja
L3899: make           -
L3900: emcc           -
L3901: node           /c/Program Files/nodejs/node
L3902: npm            /c/Program Files/nodejs/npm
L3903: pio            /c/Users/Liang/.local/bin/pio
L3904: idf.py         -
L3905: kicad-cli      -
L3906: wolframscript  -
L3907: openscad       -
L3908: contrib-piohome
L3909: framework-arduinoespressif32
L3910: toolchain-riscv32-esp
L3911: toolchain-xtensa-esp32s3
L3912: tool-esptoolpy
L3913: tool-mkfatfs
L3914: tool-mklittlefs
L3915: tool-mkspiffs
L3916: tool-scons
L3917: Mathematica
L3918: WolframScript
L3919: Shell cwd was reset to c:\Users\Liang\tigp-2026
L3920: Agent:Audit class-board electronics
L3921: IN
L3922: You are auditing the electronics of a low-field NMR teaching instrument for a from-scratch redesign. READ-ONLY: do not edit, commit, or run git commands that change state in these repos. Write any generated reports only under C:\Users\Liang\AppData\Local\Temp\claude\audit-electronics\ (create it).
L3923: 
L3924: Repository: C:\Users\Liang\tigp-2026\class-board-2026 (branch w1-yi-tsai, identical to the archive under audit). The board is an ESP32-S3 based NMR console: ~2.1 mT B0, proton Larmor ~89.4 kHz, IF 5.4 kHz. Key places: hardware/*.kicad_sch (main board, many sheets incl. NMR TX and NMR RX), hardware/front-panel/, hardware/docs/ (requirements.md, design-decisions.md, design-review.md, bring-up.md, student-deletions.md), hardware/scripts/ (sheet_nmr_tx.py, sheet_nmr_rx.py, gen_sch.py etc. which GENERATE schematics - useful to read component values), firmware/NMR-FIRMWARE.md, firmware/include/pins.h, workbook/blocks/*.md, docs/references.md. KiCad CLI: C:\Users\Liang\AppData\Local\Programs\KiCad\10.0\bin\kicad-cli.exe (KiCad 10).
L3925: 
L3926: Tasks:
L3927: 1. Run ERC on hardware/class-board.kicad_sch and hardware/front-panel/front-panel.kicad_sch, and DRC on the two .kicad_pcb files, writing JSON/RPT reports to the output dir above. Summarise counts by severity and the top distinct violation types. If a run fails, report the exact error. (Library path variable: the project may need --define-var TIGP_BOARD_LIB=C:\Users\Liang\tigp-2026\class-board-2026\hardware\lib or similar; check hardware/README.md / SETUP.md for the variable name.)
L3928: 2. Export a netlist (kicad-cli sch export netlist) of the main board to the output dir; use it to verify connectivity claims below.
L3929: 3. Audit, with exact component references and values and file:line or sheet sources:
L3930:    - TX chain: DDS (AD9834?), any filter, power amplifier (OPA564?), series elements (R813, C818?), output to the TX COIL terminal (J32), max output voltage/current, current-limit/flag pins.
L3931:    - RX chain: RX SMA input, crossed-diode protection (D703/D704?), tank capacitors (C710/C711/C712), LNA, blanking switch (DG419?), mixer/LO (Si5351?), IF filtering and gain, ADC (ADS8688) input range and which channels.
L3932:    - Whether TX and RX share one coil in the intended use, and quantify the loading of the transmitter by the RX protection diodes when the same coil is on both (current through the series resistor). Check whether any T/R switch exists.
L3933:    - B0 drive: H-bridge (DRV8871?) on J903, its supply (+VEXT range), current limit / ILIM resistor value and resulting I_TRIP, whether there is any current sensing of the B0 coil current, and whether the DRV8871 regulates current (cite its datasheet behaviour only if you are sure).
L3934:    - Polarizer FET path (J905), relays, power rails, grounding / analog-digital separation, clock sources.
L3935:    - ADC: ADS8688 SPI wiring (which ESP32 pins, SPI host), its range setting, and anything relevant to sustained sample rate.
L3936: 4. List every critical numeric parameter you find (frequencies, gains, bandwidths, component values, limits) as a table: name, value, unit, source file:line.
L3937: 5. Classify each significant hardware feature/finding as RETAIN, REIMPLEMENT, VERIFY, or REMOVE with one-line justification, and list known problems / risks (with evidence).
L3938: 
L3939: Report concisely but completely (aim for under ~1500 words plus tables). Include the exact paths of the report files you wrote. Do not speculate without labelling it as such.
L3940: Agent:Audit firmware, DSP and host
L3941: IN
L3942: You are auditing the firmware and host software of a low-field NMR teaching instrument (ESP32-S3, ~89.4 kHz proton line, 5.4 kHz IF) for a from-scratch redesign. READ-ONLY: do not edit files or change git state. You may build in a COPY if you want to measure something, but only under C:\Users\Liang\AppData\Local\Temp\claude\audit-firmware\.
L3943: 
L3944: Repository: C:\Users\Liang\tigp-2026\class-board-2026 (branch w1-yi-tsai). Firmware: firmware/ (PlatformIO; platformio.ini, src/, include/pins.h, src/drivers/ for SPI lock, TCA9535, Si5351A, AD9834, ADS8688; src/blocks/nmr/ Sequencer.cpp/.h, Dsp.cpp/.h, NmrBlock.cpp/.h; other blocks b1..b5, base, alarms). Docs: firmware/NMR-FIRMWARE.md, firmware/PROTOCOL.md, CLAUDE.md. Host: host/instrument.py, host/pwa/ (panels/nmr.js etc.).
L3945: 
L3946: Tasks:
L3947: 1. Describe precisely how one NMR scan is timed and executed today (functions, file:line): pulse gating mechanism (digitalWrite + busy wait?), timer used, task/core, priorities, interrupt use, how ADC sampling is paced (esp_timer polling? per-sample SPI?), buffer allocation (heap_caps_malloc at config? per scan?), averaging, CYCLOPS, DSP (offset removal, mixing, decimation by boxcar, etc.), and what goes over the network.
L3948: 2. ADS8688 driver: what SPI mode/host/clock/transactions it actually uses vs what NMR-FIRMWARE.md and any comments claim. Report EVERY discrepancy between docs and code (exact quotes + file:line). Estimate per-sample overhead and the max realistic sustained rate from the code structure (label as estimate).
L3949: 3. AD9834 and Si5351 drivers: how frequency/phase are set, register sequences, resolution (Hz per LSB), reference clocks, and whether phase switching for CYCLOPS/echo is possible within a sequence.
L3950: 4. Hard-real-time hazards: any heap allocation, logging, JSON, WiFi, String, filesystem, mutex waits inside the timing path; jitter sources.
L3951: 5. Host side: instrument.py nmr command and nmr_spectrum (note the Hann window over the whole record); PWA nmr.js: what it computes (its own DSP/FFT?), any duplicated physics/DSP between firmware, JS and Python.
L3952: 6. List every hard-coded NMR/instrument constant (frequencies, t90, dead time, acquisition times, rates, decimation, gains, limits) with value, unit, file:line - note duplicates across files and inconsistencies.
L3953: 7. Check whether the SIM build compiles: run `pio run -d <copy of firmware> -e esp32s3-sim` in a copy under the audit dir (PlatformIO is at C:\Users\Liang\.local\bin\pio); report success/failure and flash/RAM usage. Note what tests exist (CI workflow .github/workflows/build.yml).
L3954: 8. Classify each significant feature as RETAIN, REIMPLEMENT, VERIFY, or REMOVE with one-line justification, and list known problems with evidence.
L3955: 
L3956: Report concisely but completely (aim under ~1500 words plus tables), with file:line citations. Label estimates and speculation clearly.
L3957: Agent:Audit simulators and physics
L3958: IN
L3959: You are auditing the NMR physics/simulation code of a low-field NMR teaching project (2.1 mT, proton ~89.4 kHz) for a from-scratch rewrite with a shared C++ physics core. READ-ONLY: do not edit files or change git state; scratch output only under C:\Users\Liang\AppData\Local\Temp\claude\audit-physics\.
L3960: 
L3961: Repositories:
L3962: - C:\Users\Liang\tigp-2026\nmr-instrument (main @ 0914edb): simulator/physics.js (Bloch/voxel model), simulator/index.html, simulator/m/fieldmap-tube.json and fieldmap-bottle.json, simulator/build/nmr_exact.wls (Mathematica Biot-Savart + SpinDynamica checks), simulator/build/compact.py, simulator/build/test-physics.js, simulator/README.md; mechanical/spectrum.py (Python simulator: Helmholtz 4th-order field over the sample, dead time, tank, coil heating drift, field sweep), mechanical/nmr-params.scad and probe.scad (constants), mechanical/instrument.scad (cross-checks).
L3963: - C:\Users\Liang\tigp-2026\class-board-2026 (branch w1-yi-tsai): firmware/src/blocks/nmr/Sequencer.cpp SIM branch (simulated FID), Dsp.cpp, host/instrument.py.
L3964: Mathematica: C:\Program Files\Wolfram Research\WolframScript\wolframscript.exe (Mathematica 13.3). Node is available (node). Python 3.11 with numpy is `py`.
L3965: 
L3966: Tasks:
L3967: 1. For each physics model (physics.js, spectrum.py, nmr_exact.wls, firmware SIM), list: what equations it implements (Bloch rotation, relaxation, off-resonance, B1 profile, reciprocity, tank, noise, detection/I-Q sign convention, field model), units, assumptions, and file:line.
L3968: 2. Check correctness against analytic cases where possible: run test-physics.js; if feasible run nmr_exact.wls (or report how long/why not); spot-check: Curie magnetization formula, Helmholtz 4th-order coefficient (144/125 along axis, 3/8*144/125 radial), finite-solenoid on-axis field, rotating-frame B1 = half linear field, t90 = pi/(2*gamma*B1), Hahn echo refocusing, sign of precession (I/Q convention), T1/T2. Report any errors or inconsistencies with evidence and numbers.
L3969: 3. Field maps: format of fieldmap-*.json (what grid, units, what quantities), how they were produced, whether they're trustworthy and reusable as golden data.
L3970: 4. Inventory of physics/instrument constants across these files (gamma, B0, I, turns, R, coil L/R/Q, tank C, fTank, t90, dead time, rates, noise density, gains, T1/T2, sample geometry) with value, unit, file:line; flag duplicates and disagreements (e.g. 451 us vs 417 us t90; fTank values; coil radius).
L3971: 5. Performance: where the hot loops are (e.g., O(N*voxels) time stepping, naive DFT in spectrum()), measured runtime if you can run it in node quickly.
L3972: 6. Classify each significant feature as RETAIN, REIMPLEMENT, VERIFY, or REMOVE with one-line justification. Identify which outputs are trustworthy enough to be golden reference data for new tests (with the exact numbers to use and their provenance).
L3973: 
L3974: Report concisely but completely (aim under ~1500 words plus tables), with file:line citations; label estimates.
L3975: wasi-sdk 25 is built on LLVM 19, matching the installed Clang. I'll download its sysroot (65 MB) and builtins to C:\Users\Liang\tools\wasi.
L3976: 
L3977: 
L3978: 
L3979: Bash Download and unpack WASI sysroot and builtins
L3980: IN
L3981: mkdir -p /c/Users/Liang/tools/wasi && cd /c/Users/Liang/tools/wasi && curl -sL -o sysroot.tgz https://github.com/WebAssembly/wasi-sdk/releases/download/wasi-sdk-25/wasi-sysroot-25.0.tar.gz && curl -sL -o rt.tgz https://github.com/WebAssembly/wasi-sdk/releases/download/wasi-sdk-25/libclang_rt.builtins-wasm32-wasi-25.0.tar.gz && tar xzf sysroot.tgz && tar xzf rt.tgz && rm *.tgz && ls && find . -maxdepth 3 -name "*.a" | head -5; ls wasi-sysroot-25.0/lib
L3982: 
L3983: OUT
L3984: Command did not complete within its 600s timeout and was moved to the background (ID: buzuc7hmv). Output is being written to: C:\Users\Liang\AppData\Local\Temp\claude\c--Users-Liang-tigp-2026\a1274a3c-ba83-4c3b-98af-0f75dbaec45f\tasks\buzuc7hmv.output. You will be notified when it completes. If it is still running after 30m in the background, it will be stopped and you will be notified. To check interim output, use Read on that file path.
L3985: Session cwd remains C:\Users\Liang\tigp-2026; directory changes made by the backgrounded command do not apply to subsequent commands.
L3986: Bash
L3987: IN
L3988: cd /c/Users/Liang/tigp-2026/class-board-2026/hardware; ls sheets; grep -c '"AGND"' *.kicad_sch sheets/*.kicad_sch 2>/dev/null; grep -o '(lib_id "[^"]*AGND[^"]*")' -r sheets class-board.kicad_sch | sort | uniq -c | head; grep -n -i "agnd" docs/design-decisions.md | head -20
L3989: 
L3990: OUT
L3991: b1_inputs.kicad_sch
L3992: b2_power.kicad_sch
L3993: b3_outputs.kicad_sch
L3994: b5_dio_trig.kicad_sch
L3995: base_mcu.kicad_sch
L3996: c_switch.kicad_sch
L3997: front_panel_link.kicad_sch
L3998: nmr_rx.kicad_sch
L3999: nmr_tx.kicad_sch
L4000: class-board.kicad_sch:1
L4001: sheets/b1_inputs.kicad_sch:5
L4002: sheets/b2_power.kicad_sch:0
L4003: sheets/b3_outputs.kicad_sch:0
L4004: sheets/b5_dio_trig.kicad_sch:0
L4005: sheets/base_mcu.kicad_sch:0
L4006: sheets/c_switch.kicad_sch:0
L4007: sheets/front_panel_link.kicad_sch:0
L4008: sheets/nmr_rx.kicad_sch:0
L4009: sheets/nmr_tx.kicad_sch:1
L4010: 53:  traces/pours (+5V_RAW 1.0 mm min, other rails 0.5 mm min).  AGND is outer-layer copper joined to GND at NT1 only.
L4011: 80:## D-04 ±12 V modules: minimum-load bleeders and AGND reference
L4012: 104:- Done: /LDAC = AGND (synchronous updates), /CLR pulled up to +5VA (10 k), VREF_DAC decoupled with 1 µF and used as the
L4013: 136:## D-10 AGND–GND star: KiCad net tie NT1
L4014: 139:  the B1/BASE boundary next to the ADC.  No other AGND–GND join exists (ERC: separate nets; DRC: net-tie exception only).
L4015: 189:12 I2C_SCL · 13 TRIG_IO · 14 GPIO43 · 15 GPIO44 · 16 AUX_HDR · 17 COND_OUT2 · 18 AGND · 19/20 n/c.
L4016: 212:  DAC/op-amp block to the right-front (AO1/AO2 ≈ 60 mm along the front lane over the AGND pour; op-amp outputs with
L4017: 215:## D-21 AGND copper strategy (2026-09-08)
L4018: 217:- AGND pours on F.Cu and B.Cu over the analog band and the ±12 V output area of B2; solid pad connection; islands
L4019: 218:  removed.  Fine-pitch AGND pins (ADC, DAC, PGA) get a via to the B.Cu pour at the end of their escape stub because a
L4020: 219:  thermal spoke cannot pass between 0.5 mm-pitch pads; other AGND pads either lie in open pour or get a short track to
L4021: 220:  the nearest open pour spot.  Pour fragments that carry AGND copper are bridged by 0.5 mm tracks/vias (router pass).
L4022: 221:- L2/L3 stay unbroken GND (D-01); AGND and GND meet only at NT1.
L4023: 234:- `analog_in_clearance` 0.3 mm applies to ANALOG_IN tracks against everything except AGND (the alternating AGND link
L4024: 235:  pins and the AGND pour are the guard, not a threat).
L4025: 266:- Panel copper is AGND on both layers (solid pad connection); GND is a routed net (LED cathodes, OLED GND, link GND
L4026: 267:  pins).  Analog-input tracks keep 0.3 mm from everything but AGND (panel DRU).
L4027: 288:- At 0.5 mm pin pitch (ADS8688, DAC8563, PGA113) an AGND pin between two signal pins can never receive its own via
L4028: 290:  gives every AGND/GND pin of a fine-pitch IC a short stub *inward* (0.45 mm past the pad end, under the body), joins
L4029: 292:  the B.Cu AGND pour (or the GND planes) fits.  The signal pins keep their outward escapes; nothing else may run under
L4030: Bash Find tests and host files
L4031: IN
L4032: cd /c/Users/Liang/tigp-2026/class-board-2026 && find . -path ./firmware/.pio -prune -o \( -iname "*test*" -o -name "pyproject.toml" \) -print | grep -v node_modules | head; ls host host/pwa host/pwa/panels; git log --oneline -3
L4033: 
L4034: OUT
L4035: ./.git/subtree-cache/354/latest_new
L4036: ./.git/subtree-cache/354/latest_old
L4037: ./hardware/lib/class_board.pretty/TestPoint_Pad_D1.5mm.kicad_mod
L4038: ./host/pyproject.toml
L4039: host:
L4040: instrument.py
L4041: pwa
L4042: pyproject.toml
L4043: 
L4044: host/pwa:
L4045: app.js
L4046: dev-nmr.html
L4047: icon.svg
L4048: index.html
L4049: manifest.webmanifest
L4050: panels
L4051: style.css
L4052: sw.js
L4053: 
L4054: host/pwa/panels:
L4055: alarms.js
L4056: b1.js
L4057: b2.js
L4058: b3.js
L4059: b4.js
L4060: b5.js
L4061: base.js
L4062: nmr.js
L4063: template.js
L4064: da56d2b Project 3 (Yi-Tsai): keep only the course hand-in here; the project lives in nmr-instrument
L4065: c962f46 Project 3 (Yi-Tsai): simulator shows the sample - water voxels in place inside a see-through probe
L4066: 05d147b Project 3 (Yi-Tsai): link the live NMR bench simulator from the walkthrough
L4067: Grep "(?i)agnd.{0,40}(merged|single|one ground|retired|removed|dropped|gone)|single ground|one ground net|NT1.{0,60}(removed|gone|deleted)" (in C:\Users\Liang\tigp-2026\class-board-2026\hardware, glob: *.md)
L4068: 2 lines of output
L4069: Bash Inspect dev-nmr.html for duplicated sim/DSP
L4070: IN
L4071: cd /c/Users/Liang/tigp-2026/class-board-2026/host/pwa && wc -l dev-nmr.html && grep -n "89400\|84000\|5400\|0.018\|T2\|417\|fft\|hann\|function " dev-nmr.html | head -30
L4072: 
L4073: OUT
L4074: 142 dev-nmr.html
L4075: 39:    const IF_HZ = 5400;
L4076: 41:    const AMP_V = 0.018;         // about what the receiver gives for water at 2 mT
L4077: 42:    const T2_S = 0.4;
L4078: 45:    let status = { state: 'idle', scan: 0, n_avg: 1, f_tx_hz: 89400, f_lo_hz: 84000, if_hz: IF_HZ,
L4079: 48:    function toast(text) {
L4080: 73:    function makeFrame(scans, noiseV) {
L4081: 92:        const env = AMP_V * Math.exp(-t / T2_S);
L4082: 100:    function noiseFor(scans) {
L4083: 105:    function emitFrame(scans) {
L4084: 118:    function runScans(total) {
L4085: Bash
L4086: IN
L4087: cd /c/Users/Liang/tigp-2026/class-board-2026/hardware; sed -n 77p AGENTS.md | cut -c1-1500; echo; sed -n 194,201p docs/design-review.md | cut -c1-1800; grep -n "Decision #6[0-9]\|^## D-6\|^## #6\|^### #6" docs/design-decisions.md | head -20
L4088: 
L4089: OUT
L4090: | `front-panel/sections/{A,B,C,D}/` | **2026-09-18: the panel routing is divided among the four students by NETS** (A analog, B digital + LEDs, C module outputs, D isolated inputs + 3.3 V + I2C). Each folder is a complete copy of the unrouted panel with a `SECTION.md`; `scripts/panel_sections.py split|check|merge` regenerates the copies from the master, reports what a section routed, and merges only each section's own nets (plus its GND/AGND vias) into `front-panel-merged.kicad_pcb` with a DRC run. The instructor accepts the merged board by hand. Replaces the old generated `student/front-panel/` copy. |
L4091: 
L4092: | 2 | **Transmit return current** | Up to 1 A (and 13 A at the polarizer) must return to J802 / J905; if any of it shares copper with the receiver pour it appears as a differential signal in front of a gain of 1000 | TX out and TX return both on GND, terminal on the front edge directly under the power stage; receiver entirely on AGND; single tie at NT1 | TX and its return routed as a **close pair, loop area < 1 cm²**; the coil return never touches the AGND pour; polarizer pair likewise, ≥ 2 mm wide | T-17, T-22 |
L4093: | 3 | **Coupling-capacitor recovery** | After transmit leakage saturates the LNA, an innocent 1 µF / 100 k interstage coupling (1.6 Hz) takes 300 ms to recover — four T2* periods, and the classic reason a first NMR build shows nothing | Interstage corner deliberately at **1.59 kHz** (C720 10 nF / R721 10 k): 0.3 ms recovery for 0.016 % of amplitude and 1.0° of phase at 89.4 kHz (D-39) | Do not "improve" the corner by enlarging C720; keep C720/R721 adjacent to the switch | T-19 |
L4094: | 4 | **Switch charge injection** | The DG419 injects ~60 pC.  On the 1.25 nF tank that is a 48 mV kick ringing for 36 µs at full gain; the TS5A23157 injects 3 pC LO-synchronously, which is a DC offset after the mixer | Blanking placed **between the stages**, where 60 pC lands on 10 nF as 6 mV (τ = 100 µs); mixer differential with 0.1 % difference amps (CMRR 54 dB) so the LO-synchronous injection cancels (D-38, D-39) | The two IF paths must be **mirror images** (R914–R917 as matched pairs, placed symmetrically) or the cancellation is lost | T-19, T-20 |
L4095: | 5 | **PowerPAD thermal paths** | OPA564 (0.70 W quiescent, 4.1 W in the worst continuous case) and DRV8871 (3.6 A) have no other heat path than their exposed pads | OPA564 is the **pad-down DWP part** (C188648) with the pad at V− = GND (θ_JA 33 °C/W on a high-K board); duty cycle held to ≤ 1 % by TX_EN (D-35); DRV8871 datasheet §10.1 | OPA564 pad soldered onto the GND pour with a via array; DRV8871 pad with a **3 × 3 array of 0.3 mm vias on a 1.0 mm grid** to a bottom-layer GND pour; OUT traces ≥ 2 mm; no precision part within 15 mm | T-17 thermal, T-21 |
L4096: | 6 | **+VEXT pumping and clamping** | Coil energy returns to VM (½LI² = 1.8 mJ → a 1.2 V rise on 100 µF), and no TVS both passes 24 V and clamps below the OPA564 26 V maximum | C921 100 µF sized for the 25 µs t_OFF window; SMBJ26A on VM and on the input (clamps ~42 V, below the DRV8871 45 V); ferrite + 47 µF local at the OPA564 V+; **silkscreen limit +VEXT 7–18 V** (D-41, D-42) | Bulk capacitor within a few millimetres of the DRV8871 VM pin; the OPA564 branch fed through its own ferrite, not tapped off the H-bridge node | T-14, T-21 |
L4097: 
L4098: Two more properties worth stating because they constrain the layout rather than a component: **the tank node must have
L4099: no ground pour under it** (added capacitance detunes the resonance), and **the crossed-diode limiter D703/D704 with its
L4100: Bash
L4101: IN
L4102: S=/c/Users/Liang/AppData/Local/Temp/claude/c--Users-Liang-tigp-2026/a1274a3c-ba83-4c3b-98af-0f75dbaec45f/scratchpad; $S/nl list '^(NT|TP)'; cd /c/Users/Liang/tigp-2026/class-board-2026/hardware; grep -n -i "NT1\|one GND\|single GND\|AGND.*GND.*merg\|merg.*AGND\|AGND is gone\|no AGND" docs/design-decisions.md README.md AGENTS.md | cut -c1-300 | tail -15
L4103: 
L4104: OUT
L4105: TP1 ('RST', '/base_mcu/', False)
L4106: TP2 ('GND', '/base_mcu/', False)
L4107: TP201 ('5V_RAW', '/b2_power/', False)
L4108: TP202 ('+3V3', '/b2_power/', False)
L4109: TP203 ('+12V', '/b2_power/', False)
L4110: TP204 ('-12V', '/b2_power/', False)
L4111: TP205 ('+5VA', '/b2_power/', False)
L4112: TP3 ('+3V3', '/base_mcu/', False)
L4113: TP301 ('VREF', '/b3_outputs/', False)
L4114: TP4 ('+5V', '/base_mcu/', False)
L4115: TP501 ('EXP_P14', '/b5_dio_trig/', False)
L4116: TP701 ('CLK2', '/nmr_rx/', False)
L4117: TP702 ('V_MID', '/nmr_rx/', False)
L4118: docs/design-decisions.md:53:  traces/pours (+5V_RAW 1.0 mm min, other rails 0.5 mm min).  AGND is outer-layer copper joined to GND at NT1 only.
L4119: docs/design-decisions.md:136:## D-10 AGND–GND star: KiCad net tie NT1
L4120: docs/design-decisions.md:221:- L2/L3 stay unbroken GND (D-01); AGND and GND meet only at NT1.
L4121: README.md:133:  the OPA564, the DRV8871 and the polarizer gate driver only).  AGND ↔ GND only at the net tie NT1.  L2 and L3 are
L4122: AGENTS.md:77:| `front-panel/sections/{A,B,C,D}/` | **2026-09-18: the panel routing is divided among the four students by NETS** (A analog, B digital + LEDs, C module outputs, D isolated inputs + 3.3 V + I2C). Each folder is a complete copy of the unrouted panel with a `SECTION.md`; `scripts/panel_se
L4123: AGENTS.md:158:  the OPA564 return are on GND; the two meet only at NT1.  Do not "tidy" a ground symbol from AGND to GND.
L4124: Bash
L4125: IN
L4126: cd /c/Users/Liang/tigp-2026/nmr-instrument/mechanical && py -c "
L4127: import sys; sys.argv=['x']; import spectrum as s
L4128: p=s.Probe(); print('N',p.N,'b_per_a mT/A',p.b_per_a*1e3,'line@1.5A',p.gamma*p.b_per_a*p.I0,'ohm',p.ohm,'cu kg',p.cu_kg,'x_span mm',p.x_span,'r_smp',p.r_smp,'f_tank',p.f_tank)
L4129: o=p.field_offsets(); print('offsets Hz min/max',o.min()*p.f_tx,o.max()*p.f_tx)
L4130: "; grep -n "cap_h\|hh_N\|probe_b0()\|function probe_b0\|ohm\|smp_" probe.scad | head -20
L4131: 
L4132: OUT
L4133: N 312 b_per_a mT/A 1.4027150054942124 line@1.5A 89585.09518339061 ohm 10.327360784697253 cu kg 9.196971258383721 x_span mm (-50.0, 25.0) r_smp 15.0 f_tank 89400.0
L4134: offsets Hz min/max -177.50657429490428 15.902590275580797
L4135: 75:smp_d   = 30;             // body diameter
L4136: 76:smp_l   = 115;            // overall length with the cap
L4137: 78:cap_h   = 12;
L4138: 82:sleeve_id = smp_d + fit;
L4139: 150:    cylinder(d = cap_d, h = cap_h);
L4140: 151:    translate([0, 0, cap_h]) cylinder(d = smp_d, h = smp_l - cap_h - cone_l);
L4141: 152:    translate([0, 0, smp_l - cone_l]) cylinder(d1 = smp_d, d2 = 4, h = cone_l);
L4142: 232:hh_N    = ceil(B0 * hh_R / 1000 / (pow(4 / 5, 1.5) * mu0 * hh_I));
L4143: 233:hh_h    = ceil(hh_N * hh_wd * hh_wd / 0.8 / hh_w);          // radial build at 80 % fill
L4144: 234:hh_len  = 2 * hh_N * 2 * PI * hh_R / 1000;                  // m, both coils
L4145: 235:hh_ohm  = hh_len * 1.724e-8 / (PI * pow(hh_cu / 2000, 2));
L4146: 254:        %translate([0, 0, -fl_t - cap_h]) sample_tube();
L4147: 272:function probe_b0_leads() = [0, hh_R / 2 + hh_w / 2, axis_z - hh_R - hh_h / 2];  // +y ring, bottom
L4148: 274:function probe_b0() = [hh_R, hh_I, hh_ohm, hh_N, hh_h];
L4149: 286:smp_body = [-fl_t - cap_h + cap_h, -fl_t - cap_h + smp_l - cone_l];      // tube body, former z
L4150: 287:echo(str("50 mL tube in the sleeve: body z ", smp_body[0], "..", smp_body[1], ", tip ", -fl_t - cap_h + smp_l,
L4151: 296:echo(str("B0 pair: ", B0 * 1000, " mT at ", hh_I, " A -> 2 x ", hh_N, " turns AWG16 on R = ", hh_R,
L4152: 297:         " mm, channel ", hh_w, " x ", hh_h, " mm; ", round(hh_len), " m, ", round(hh_ohm * 10) / 10, " ohm, ",
L4153: 298:         round(hh_I * hh_ohm * 10) / 10, " V, ", round(hh_I * hh_I * hh_ohm), " W, ",
L4154: 300:         hh_I < hb_trip && hh_I * hh_ohm <= vext_max));
L4155: Bash
L4156: IN
L4157: cd /c/Users/Liang/tigp-2026/class-board-2026/hardware; grep -o '(net_name "[^"]*")\|(net [0-9]* "[^"]*GND[^"]*")' class-board.kicad_pcb | sort | uniq -c | head; grep -c "(zone" class-board.kicad_pcb; grep -A3 "(zone" class-board.kicad_pcb | grep -o '(net_name "[^"]*")\|(net "[^"]*")\|(layers\? [^)]*)' | sort | uniq -c; grep -o '(layers "[^"]*" "[^"]*"[^)]*)' class-board.kicad_pcb | head -2; grep -n '(layers' class-board.kicad_pcb | head -3; sed -n '/^\t(layers/,/^\t)/p' class-board.kicad_pcb | head -12; grep -i "AGND\|GND" front-panel/front-panel.kicad_pcb | grep -o '(net "[^"]*")' | sort | uniq -c
L4158: 
L4159: OUT
L4160: 14
L4161:       9 (layer "F.Cu")
L4162:       1 (layers "F.Cu" "B.Cu" "In1.Cu" "In2.Cu")
L4163:       4 (layers "F.Cu" "B.Cu")
L4164:       1 (net "/b1_inputs/TX")
L4165:       1 (net "/c_switch/COIL")
L4166:       1 (net "/c_switch/HB_OUT1")
L4167:       1 (net "/c_switch/HB_OUT2")
L4168:       1 (net "/c_switch/VIN_F")
L4169:       1 (net "/nmr_tx/+VEXT_TX")
L4170:       1 (net "/nmr_tx/TX_A")
L4171:       1 (net "+VCOIL")
L4172:       1 (net "+VEXT")
L4173:       1 (net "GND")
L4174: (layers "F.Cu" "F.Mask" "F.Paste")
L4175: (layers "F.Cu" "F.Mask" "F.Paste")
L4176: 16:	(layers
L4177: 125:			(layerselection 0x00000000_00000000_55555555_5755f5ff)
L4178: 345:			(layers "F.Cu" "F.Mask" "F.Paste")
L4179: 	(layers
L4180: 		(0 "F.Cu" signal)
L4181: 		(4 "In1.Cu" power)
L4182: 		(6 "In2.Cu" power)
L4183: 		(2 "B.Cu" signal)
L4184: 		(9 "F.Adhes" user "F.Adhesive")
L4185: 		(11 "B.Adhes" user "B.Adhesive")
L4186: 		(13 "F.Paste" user)
L4187: 		(15 "B.Paste" user)
L4188: 		(5 "F.SilkS" user "F.Silkscreen")
L4189: 		(7 "B.SilkS" user "B.Silkscreen")
L4190: 		(1 "F.Mask" user)
L4191:     215 (net "GND")
L4192: Bash
L4193: IN
L4194: cd /c/Users/Liang/tigp-2026/class-board-2026 && grep -n -i -E "hann|fft|conj|larmor|ppm|gamma|window|f_lo \+|lo \+" host/instrument.py | head -20; grep -rn -E "15\.6|1\.02|40e-6|40 uV|gain" ../nmr-instrument/simulator/index.html | head -10; grep -n -E "P\.|NMR\.|t90|451|417|tau" ../nmr-instrument/simulator/index.html | head -40
L4195: 
L4196: OUT
L4197: 288:    """Return (freq_hz, amplitude) for a complex record: Hann window, FFT, fftshift.
L4198: 290:    freq_hz is relative to the local oscillator, so the Larmor frequency of a line
L4199: 291:    at f is f_lo + f. Imports numpy.
L4200: 299:    w = np.hanning(n)
L4201: 300:    spec = np.fft.fftshift(np.fft.fft(z * w)) * (2.0 / w.sum())
L4202: 301:    freq = np.fft.fftshift(np.fft.fftfreq(n, d=1.0 / rate_hz))
L4203: 333:    """Run one NMR scan set and print the peak, the Larmor frequency and the SNR."""
L4204: 352:                        "larmor_hz": round(lo + peak_hz, 2),
L4205: 206:            <span class="why">Voltage-driven, <span class="num">23 W</span> warms 9.2 kg of copper by 0.39 K/min: the line falls <span class="num">138 Hz/min</span>, 7 Hz between averaged scans against a ~2 Hz line. Drive B0 at constant current, or measure it each scan and correct f_LO.</span></li>
L4206: 210:            <span class="why"><span class="num">15.6 V</span> of the 18 V rail at <span class="num">1.5 A</span> of the H-bridge's 2 A trip.</span></li>
L4207: 217:      <p class="foot">Built from <code>instrument.scad</code>, <code>probe.scad</code>, <code>housing.scad</code> and <code>cut-housing.scad</code> (<code>mechanical/</code> in this repository), 2 Oct 2026. The pulse experiment solves the Bloch equations for every voxel of the water (2.5 mm grid, 3555 voxels in the tube) in exact fields computed in Mathematica (<code>build/nmr_exact.wls</code>): Biot–Savart for the B0 pair with its real winding cross-section and for each of the class coil's 400 turns, including the direction of B1 at every voxel. With identical inputs it matches SpinDynamica (Bengs and Levitt, Magn. Reson. Chem. 2017, doi:10.1002/mrc.4642) to 0.1 % in signal, 1 Hz in line position and 1 % in T2*. Then reciprocity pickup, the Q = 10 tank and the receiver noise (15.6 nV/√Hz over 15 kHz). Shown in the frame rotating at f_tx: in the lab the magnetization turns 89 400 times a second.</p>
L4208: 235:    { id: "sample", grp: "Probe", name: "50 mL sample tube", d: "Water, 30 × 115 mm; the cap is the end stop against the sleeve.", mat: "glass", ex: [-160, 0, 0] },
L4209: 437:    if (tg < 0.8) a.push(`The line is ${fmt(Math.abs(s.fLine - NMR.P.fTank))} Hz from the tank's ${fmt(NMR.P.fTank)} Hz, which keeps ${Math.round(tg * 100)} % of its gain.`);
L4210: 158:          <label for="c-tau">Pulse length</label><input type="range" id="c-tau" min="50" max="1500" step="1" value="417"><output id="o-tau" class="num" for="c-tau">417 µs</output>
L4211: 202:            <span class="why">All 400 turns, exactly: the second layer holds only 178 turns (x −50 … +30 mm), so B1 at the coil centre is <span class="num">14.07 µT</span> rotating and 90° takes <span class="num">417 µs</span>, as the workbook says. (The approximate model assumes an even winding and gives 451 µs.)</span></li>
L4212: 375:  const ctl = { tau: $("c-tau"), ftx: $("c-ftx"), b0: $("c-b0"), earth: $("c-earth") };
L4213: 379:  const params = () => ({ sample, nAvg, seed, fields, tau: +ctl.tau.value, fTx: +ctl.ftx.value, b0I: +ctl.b0.value, earthPar: +ctl.earth.value, earthPerp: 0 });
L4214: 381:    $("o-tau").textContent = ctl.tau.value + " µs";
L4215: 388:    sim = NMR.setup(params());
L4216: 395:    spec = NMR.spectrum(sim, specRange[0], specRange[1], 360);
L4217: 420:      ["90° at the centre", fmt(s.t90Centre * 1e6) + " µs"],
L4218: 434:    const a = [], tg = s.tankGain / NMR.P.Q;
L4219: 436:    if (Math.abs(s.flipCentre - 90) > 8) a.push(`The pulse tips ${s.flipCentre.toFixed(0)}° at the centre. <button class="mini" data-fix="tau">Set ${fmt(s.t90Centre * 1e6)} µs for 90°</button>`);
L4220: 437:    if (tg < 0.8) a.push(`The line is ${fmt(Math.abs(s.fLine - NMR.P.fTank))} Hz from the tank's ${fmt(NMR.P.fTank)} Hz, which keeps ${Math.round(tg * 100)} % of its gain.`);
L4221: 441:      if (b.dataset.fix === "ftx") ctl.ftx.value = Math.round(sim.fLine); else ctl.tau.value = Math.round(sim.t90Centre * 1e6);
L4222: 456:      ctx.fillStyle = css("--line"); ctx.fillRect(X(0), Tp, X(NMR.P.tDead) - X(0), h - Tp - B);
L4223: 480:      const L = 8, R = 8, Tp = 10, B = 30, f0 = specRange[0], f1 = specRange[1], done = tPost >= NMR.P.tAcq;
L4224: 492:      const fTxIF = NMR.P.fIF;
L4225: 515:    NMR.state(sim, t, st);
L4226: 534:    const on = t > 0 && t < sim.tau;
L4227: 546:    if (reduce) { setSpin(sim.tau + 0.05); drawPlots(Infinity); return; }
L4228: 663:      const td = now / 1000 - firing, t = realTime(td), tPost = t - sim.tau;
L4229: 666:      const phase = t < sim.tau ? "pulse on: B1 tips M" : tPost < NMR.P.tDead ? "receiver blanked, M dephasing" : "recording the FID";
L4230: 671:      if (tPost >= NMR.P.tAcq) { firing = null; pulseBtn.disabled = false; drawPlots(Infinity); $("clock-t").textContent = "Record complete: 200 ms"; }
L4231: 676:  NMR.loadFieldMaps("m/").then(() => { runSim(); settle(); });
L4232: Bash Check HW build warnings and toolchain versions
L4233: IN
L4234: cd /c/Users/Liang/AppData/Local/Temp/claude/audit-firmware && grep -ci "warning" build-hw.log; grep -i "copy_pwa\|PLATFORM:\|framework-arduino" build-sim.log | head -4
L4235: 
L4236: OUT
L4237: 0
L4238: Processing esp32s3-sim (platform: espressif32 @ ^7.1.1; board: esp32-s3-devkitc-1; framework: arduino)
L4239: copy_pwa: copied 15 files from C:\Users\Liang\AppData\Local\Temp\claude\audit-firmware\fw\host\pwa -> C:\Users\Liang\AppData\Local\Temp\claude\audit-firmware\fw\firmware\data
L4240: PLATFORM: Espressif 32 (7.1.2) > Espressif ESP32-S3-DevKitC-1-N8 (8 MB QD, No PSRAM)
L4241:  - framework-arduinoespressif32 @ 4.20017.260907+sha.dcc1105b
L4242: Bash
L4243: IN
L4244: S=/c/Users/Liang/AppData/Local/Temp/claude/c--Users-Liang-tigp-2026/a1274a3c-ba83-4c3b-98af-0f75dbaec45f/scratchpad; py -3 $S/fp.py list '^(K|U|RLY|Q)'; cd /c/Users/Liang/tigp-2026/class-board-2026/hardware; sed -n 21,24p docs/student-deletions.md; sed -n 50,70p docs/bring-up.md | cut -c1-700; grep -c "(segment" class-board.kicad_pcb
L4245: 
L4246: OUT
L4247: Q411 ('MMBT5551', '/', False)
L4248: Q412 ('MMBT5551', '/', False)
L4249: Q421 ('MMBT5551', '/', False)
L4250: Q422 ('MMBT5551', '/', False)
L4251: U401 ('6N137S-TA1-L', '/', False)
L4252: U402 ('6N137S-TA1-L', '/', False)
L4253: U410 ('SN74AHCT541PWR', '/', False)
L4254: H-bridge and the polarizer (Decision #58, 2026-09-17). The former `b4_switching` sheet (relays, mains) no longer exists.
L4255: 
L4256: Each section also adds its one JLC-library part: fetch the symbol + footprint with the JLC/LCSC part number
L4257: above, check the pin numbering and the footprint against the datasheet, and commit it to `lib/class_board`.
L4258: | **T-14 +VEXT and +3V3A rails** | USB only, then 12 V on J901 through a 0.5 A current limit, then 18 V; nothing else connected | +VEXT at C940, drop across Q901, +3V3A at C905, +VEXT LED | +VEXT = V_in − (I·0.015 Ω) ≈ V_in; reverse polarity on J901 draws **0 mA** (P-FET blocks); +3V3A = 3.30 ± 0.06 V and its ripple ≤ 10 mVpp; LED on from 7 V | any current with the input reversed, or +VEXT missing → check F901/Q901/D932 | R-42, D-41 |
L4259: | **T-15 Si5351 outputs and the quadrature LO** | USB only; firmware sets PLLA → CLK0 = 50.000 MHz, PLLB → CLK1 = 336.000 kHz (= 4 × 84 kHz), then pulses /CLR (expander P1.4) | scope on CLK0 (TP/R703), CLK1 (R704) and on LO_I / LO_Q at the U702 outputs, two channels, 50 % trigger | CLK0 50.000 MHz ± 10 ppm square; CLK1 336.000 kHz; **LO_I and LO_Q at exactly 84.000 kHz, 50 % duty, phase difference 90° ± 2°**, and the same phase relation after every /CLR pulse and every PLLB retune | no 90°, or a phase that moves between runs → /CLR is not being pulsed (D-33) | R-37 |
L4260: | **T-16 DDS output and the reconstruction filter** | USB only, TX_EN low; firmware writes FREQ0 for 89.400 kHz, then sweeps 10 kHz → 2 MHz | scope (and, if available, a spectrum measurement) at the C810 filter output, before the power stage | 0.636 V pp ± 10 % sine at 89.400 kHz ± 0.2 Hz; passband flat to 2 MHz within 0.5 dB; no visible 48 MHz image on a 100 MHz scope; DDS phase register toggling with PSELECT shifts the phase by 90°/180° | level below 0.5 V pp → check R801/R802; steps in the sweep → L801 substituted | R-34, D-34 |
L4261: | **T-17 OPA564: gain, current limit, thermal flag** | +VEXT = 18 V (after USB), **10 Ω 20 W dummy load** from the TX terminal J802 to GND, DDS at 89.4 kHz, TX_EN pulsed 1 ms at 1 % duty; then a continuous burst for the thermal check | output amplitude at J802, I_FLAG and T_FLAG (expander inputs), supply current, package temperature after 5 min | 15.9 V pp ± 5 % (G = 25.0, JP801 = 270 Ω); no I_FLAG at 1 ms/1 %; with the load reduced to 4.7 Ω the current limit asserts I_FLAG near **1.5 A** (R809 = 11.0 k); package < 70 °C at 1 % duty; output sits at V_mid ≈ 9 V between pulses | flags stuck high, or an output offset ≠ V_mid → stop: check E/S (R810), ISET (never open) and the pad-dow
L4262: | **T-18 LNA gain with a 40 µV signal** | generator 40 mV pk at 89.4 kHz into a **60 dB attenuator** → RX SMA (J703, panel row 2 column 5); tank capacitors fitted; RX_BLANK high (receive); TX off | scope at the stage-2 output (U703 pin 7) with a ×10 probe; then repeat with JP702 set to G = 11 | ≈ 40 mV pk at the LNA output (gain 1000 ± 10 %, or ±2 % of the 1 % gain-resistor tolerance plus the 9.1 k substitution of D-49); noise floor ≤ 2 mV rms in a 15 kHz bandwidth; G = 11 setting gives ≈ 4.4 mV | gain low by more than 20 % → tank detuned (tune at the coil, not on the board) | R-35, D-36 |
L4263: | **T-19 Blanking timing and recovery** | same signal as T-18; firmware drives RX_BLANK: low ≥ 20 µs before TX_EN, TX pulse 417 µs, TX_EN low, 1 ms wait, RX_BLANK high | scope: RX_BLANK, TX_EN and the stage-2 output on one screen, 1 ms/div and 100 µs/div | receiver silent while RX_BLANK = 0; with RX_BLANK **un-driven** the receiver is blanked (D-39); after RX_BLANK rises the output settles to within 1 % of baseline in **≤ 1 ms**; charge-injection step at the switch ≤ 10 mV referred to the stage-2 input | recovery > 3 ms → the interstage coupling was built with the wrong corner (C720/R721, D-39) | R-36 |
L4264: | **T-20 I/Q outputs at the ADC** | generator at **f_LO + 5 kHz** and then **f_LO − 5 kHz** (40 mV pk through the 60 dB attenuator) into RX; LO at 84.000 kHz; JP101/JP102 in the mixer position; firmware streams ADS8688 channels 7 and 8 at 250 kS/s | scope at COND_OUT1/COND_OUT2 and the streamed ADC records; complex FFT of I + jQ | two sine waves at 5 kHz, equal amplitude within 1 dB, **90° apart**; ≈ 1.0 V pk on each channel for a 40 µV input (6540 LSB); the complex FFT shows the line on the **+5 kHz side for f > f_LO and the −5 kHz side for f < f_LO**; DC offset at the ADC ≤ 20 mV with no input | one sideband missing → the mixer is running half-wave (R901/R902 or the U902 input 
L4265: | **T-21 H-bridge into a resistive load** | +VEXT = 12 V with the supply current limit at 3 A; **10 Ω 20 W** across J903; firmware drives HB_IN1/HB_IN2 forward, reverse, brake, coast, 10 ms pulses | current through the load (scope probe on a series 0.1 Ω or a current clamp), voltage at J903, VM rail | 1.2 A ± 5 % at 12 V into 10 Ω in both directions; coast at reset (both inputs low, 10 k pull-downs); with the load reduced to 4.7 Ω the current regulates at **2.0 A** (R920 = 32.0 k, I_TRIP = 64/R_ILIM); VM rise during a switching burst ≤ 1.5 V (C921 = 100 µF) | no regulation, or VM rising above 20 V → check R920 and C921 before connecting a coil | R-40, D-42 |
L4266: | **T-22 Polarizer switch and freewheel decay** | separate supply on J905 pins 1/3 at **5 V, 2 A limit**, small air-core coil (≈ 1 mH, few Ω) between pins 1 and 2, D930 SS54 fitted, D934 not fitted; FET_GATE pulsed 100 ms at 0.1 Hz | scope on the drain (J905 pin 2) with a ×10 probe, current through the coil, Q904 tab temperature | coil current rises to V/R and switches off with **τ = L/R_coil** (exponential, no overshoot beyond V_supply + 0.6 V with the freewheel diode fitted); peak drain voltage **well below 40 V**; ISENSE_COIL shows the current if R933 is swapped for the 10 mΩ shunt (fitted 0 Ω by default, D-44); Q904 barely warm at this duty | any drain excursion above 30 V → sto
L4267: | **T-23 Power sequencing** | with a scope on VDIG (+3V3) and V+ (+VEXT): (a) correct order — USB on, 2 s, bench supply on; (b) deliberately wrong order on a board whose U802 is **not yet fitted** | supply currents, OPA564 behaviour, flags after each sequence | (a) no current step beyond the expected quiescent 39 mA, TX quiet, flags clear; (b) documents the hazard only — **never run the wrong order with U802 fitted** (the datasheet marks it not allowed) | any latch-up-like current step in (a) → stop | R-43, D-35 |
L4268: 
L4269: Firmware channel table (D-19) required for T-06: `AI1→6, AI2→7, AI3→0, AI4→1, AI5→2, AI6→3, AI7→4, AI8→5`
L4270: (ADS8688 channel select bits = AIN index).
L4271: 
L4272: NMR sequence used by T-19 / T-20 (circuits doc §9.3): RX_BLANK low ≥ 20 µs before TX_EN high; TX_EN high for the pulse
L4273: (417 µs = 90°, 834 µs = 180°); TX_EN low; wait 1 ms; RX_BLANK high; start the ADC burst 1.2 ms after the pulse.
L4274: Poll I_FLAG and T_FLAG after every pulse and abort the scan if either is set (a current-limit flag means the coil or
L4275: the gain jumper is wrong, a thermal flag means the duty cycle is too high).
L4276: 
L4277: Order of the v0.7 tests: T-14 → T-15 → T-16 → T-17 (power stage, dummy load only) → T-18 → T-19 → T-20, then the
L4278: high-current pair T-21 / T-22.  Do not connect a real coil to the TX terminal before T-17 passes on a dummy load.
L4279: 2634
L4280: Bash
L4281: IN
L4282: cd /c/Users/Liang/AppData/Local/Temp/claude/audit-physics && sed 's|const n = \[-w1 \* Math.cos(phi) / W, -w1 \* Math.sin(phi) / W, -dw / W\];|const n = [w1 * Math.cos(phi) / W, w1 * Math.sin(phi) / W, dw / W];|' /c/Users/Liang/tigp-2026/nmr-instrument/simulator/physics.js > physics_sdconv.js && grep -c "const n = \[w1" physics_sdconv.js && cat > conv.js <<'EOF'
L4283: const fs=require("fs");
L4284: for (const f of ["C:/Users/Liang/tigp-2026/nmr-instrument/simulator/physics.js","./physics_sdconv.js"]) {
L4285:   delete require.cache[require.resolve(f)]; const N=require(f);
L4286:   for (const k of ["tube","bottle"]) N.MAPS[k]=JSON.parse(fs.readFileSync(`C:/Users/Liang/tigp-2026/nmr-instrument/simulator/m/fieldmap-${k}.json`));
L4287:   for (const k of ["tube","bottle"]) { const s=N.setup({sample:k,fTx:89400,b0I:1.5,tau:417,earthPar:0,earthPerp:0,nAvg:1,seed:3});
L4288:     console.log(f.split("/").pop(),k,"emf uV",(s.emfUntuned*1e6).toFixed(5),"T2* ms",(s.t2s*1e3).toFixed(2),"line",s.fLine.toFixed(1)); }
L4289: }
L4290: EOF
L4291: node conv.js
L4292: 
L4293: OUT
L4294: 1
L4295: physics.js tube emf uV 0.90215 T2* ms 79.88 line 89559.5
L4296: physics.js bottle emf uV 1.64262 T2* ms 40.96 line 89559.2
L4297: physics_sdconv.js tube emf uV 0.90215 T2* ms 80.52 line 89559.6
L4298: physics_sdconv.js bottle emf uV 1.64262 T2* ms 41.52 line 89559.2
L4299: Bash
L4300: IN
L4301: cd /c/Users/Liang/tigp-2026/class-board-2026; grep -n "AI7→4\|T-17 OPA564\|1419\|2.53 mH\|59.7\|138 Hz" hardware/docs/bring-up.md hardware/docs/design-decisions.md hardware/scripts/sheet_nmr_rx.py docs/students/yi-tsai/PROGRESS.md | cut -c1-160; grep -n "15 kHz\|500 kSPS\|kSPS" hardware/docs/*.md | cut -c1-200 | head; grep -n "R805\|R806\|R820\|C813\|J10\b\|J11\b\|#66\|jumpers to headers" hardware/docs/design-decisions.md | cut -c1-250 | tail -12
L4302: 
L4303: OUT
L4304: hardware/docs/bring-up.md:53:| **T-17 OPA564: gain, current limit, thermal flag** | +VEXT = 18 V (after USB), **10 Ω 20 W dummy load** from the TX terminal J80
L4305: hardware/docs/bring-up.md:61:Firmware channel table (D-19) required for T-06: `AI1→6, AI2→7, AI3→0, AI4→1, AI5→2, AI6→3, AI7→4, AI8→5`
L4306: hardware/docs/design-decisions.md:405:  15.9 V pp = ±7.95 V = 5.6 mA into the 1419 Ω coil = t90 417 µs).  `sheet_nmr_tx.py` deviates from the circuits doc's
L4307: hardware/docs/design-decisions.md:435:## D-37 Blanking switch: DG419DY (C6581) replaces the ADG1419; pin 5 VL = +5VA
L4308: hardware/docs/design-decisions.md:437:- Parts-verified Group 2 / R2.1: **ADG1419 (C22368) is out of stock at LCSC and costs US$6.92** — the biggest
L4309: hardware/docs/design-decisions.md:443:- **Pin 5 (VL) is a real logic-supply pin on the DG419, not an ADG1419 no-connect:** it takes **+5VA**, and the
L4310: hardware/scripts/sheet_nmr_rx.py:253:        "Design coil: 400 turns AWG26, 4 cm x 10 cm, L = 2.53 mH, R_DC = 6.7 R. Tuned with 1.25 nF at f_Larmor = 89.4 kHz (
L4311: docs/students/yi-tsai/PROGRESS.md:28:- Verified: every .scad file runs with no errors or OpenSCAD warnings; STLs render as single valid solids; the simulator re
L4312: docs/students/yi-tsai/PROGRESS.md:29:- Next: the board-side decisions that block a real scan — TX/RX on one coil (RX clamp diodes across the transmitter, scan
L4313: hardware/docs/bring-up.md:54:| **T-18 LNA gain with a 40 µV signal** | generator 40 mV pk at 89.4 kHz into a **60 dB attenuator** → RX SMA (J703, panel row 2 column 5); tank capacitors fitted; RX_B
L4314: hardware/docs/design-decisions.md:347:  solder-jumper path (JP101/JP102).  The ADC's 15 kHz input filter, which blocks direct sampling, becomes the IF
L4315: hardware/docs/design-decisions.md:349:- Why not a fast ADC: **every member of the ADS868x family carries the same 15 kHz filter**, so there is no drop-in
L4316: hardware/docs/requirements.md:45:| R-10 | Input bandwidth | f-3dB = 1/(2π·1 k·1 nF) = 159 kHz; **the ADS8688 analog filter is 15 kHz, not 15 MHz** (corrected 2026-09-13 — it is the reason the NMR
L4317: hardware/docs/requirements.md:70:| R-35 | **Receiver gain and noise** | LNA gain 101 × 10 = 1000 (± the 1 % of D-49); total input-referred noise 15.6 nV/√Hz against a 14.2 kΩ tank = **NF 0.15 dB*
L4318: hardware/docs/requirements.md:73:| R-38 | **IF chain bandwidth and channel map** | passive pole 15.9 kHz (1.00 k / 10 nF) and active pole 14.2 kHz (20.0 k / 560 pF) ahead of the ADS8688 15 kHz filter;
L4319: 404:- Values: mid-rail bias R805/R806 100 k with C811/C812; gain R807 6.49 k over **a single R808 = 270 Ω** (G = 25.0 →
L4320: 408:  C813 100 µF blocks DC in the gain leg (DC gain 1); R809 **11.0 k** on ISET → I_LIM = 1.50 A (*never leave ISET open —
L4321: 688:  (J10-J26, row-major; the 18th position, J27, is empty).  OLED socket J30 (right-angle 1x4) pads at y 38 running
L4322: Bash
L4323: IN
L4324: cd /c/Users/Liang/tigp-2026/class-board-2026; grep -rn "R820\|C813" --include=*.md --include=*.py . | cut -c1-250 | head; grep -n "R820" hardware/sheets/nmr_tx.kicad_sch | head -3; grep -n '"Value" "10k"' hardware/sheets/nmr_tx.kicad_sch | head; cd hardware; git log --oneline -5 -- sheets/nmr_tx.kicad_sch 2>/dev/null
L4325: 
L4326: OUT
L4327: ./hardware/docs/design-decisions.md:408:  C813 100 µF blocks DC in the gain leg (DC gain 1); R809 **11.0 k** on ISET → I_LIM = 1.50 A (*never leave ISET open —
L4328: ./hardware/scripts/sheet_nmr_tx.py:324:    C813 = pl(c, "C813", CP_100U, pj[0], pj[1] + 24.13, 0)
L4329: ./hardware/scripts/sheet_nmr_tx.py:325:    sh.wire(R808.pin_pos(2)[0], R808.pin_pos(2)[1], C813.pin_pos(1)[0], C813.pin_pos(1)[1])
L4330: ./hardware/scripts/sheet_nmr_tx.py:326:    c.pwr_pin(C813, 2, "GND")
L4331: ./hardware/scripts/sheet_nmr_tx.py:327:    sh.text("G = 1 + R807/R808 = 1 + 6490/270 = 25.0. C813 blocks DC in the gain leg, so the DC gain is 1 and the output", 278.13, 323.85, 1.2)
L4332: ./hardware/scripts/sheet_nmr_tx.py:419:    "C813": (143.88, 54.01, 0), "JP801": (132.35, 51.82, 0),
L4333: 6704:	(text "2026-10-01: the bias node TX_VMID (R805/R806, C811/C812) now feeds the OPA564 +IN through R820 47k; C810 couples the DDS signal into the new node TX_IN. Before, C810 was coupled straight into the 10uF-bypassed bias node and almost no signal reached the amplifier."
L4334: 14019:		(property "Reference" "R820"
L4335: 14092:					(reference "R820")
L4336: 4462:			(property "Value" "10k"
L4337: 10182:		(property "Value" "10k"
L4338: 11000:		(property "Value" "10k"
L4339: 11274:		(property "Value" "10k"
L4340: 12115:		(property "Value" "10k"
L4341: 12389:		(property "Value" "10k"
L4342: 14121:		(property "Value" "10k"
L4343: 14768:		(property "Value" "10k"
L4344: 16081:		(property "Value" "10k"
L4345: 4f5eaba Final boards (2026-10-01 23:44/23:48 saves) and re-exported release STEP models
L4346: b5a8962 hardware: instructor 2026-10-01 afternoon saves synced
L4347: 147f9cc hardware: instructor 2026-10-01 saves synced (one GND net on both boards, PCB updated, R951-R958, headers DNP per Decision #73) + nmr_tx R808 -> TX_VMID, C813 removed, R805/R806 10 k (review B2)
L4348: db7e31c Schematic review fixes, part 2 (Konnect): panel RX/AUX labels + SMA labels swapped to match the main board (copper unchanged); TX_VMID -> R820 47k -> TX_IN (C810 couples into TX_IN); Q901 D/S corrected + D932 to +VEXT; R950 10k Q904 gate-source; R712 permanent (J3 pin 1 tied to pin 2); U302/C308 on +5VA; panel 6N137 VCC/VE + C401/C402 on +5V_RAW; R521-R528 DIO pull-downs; front_panel_link sheet removed from the root; change notes on six sheets; panel silk: pairing labels corrected, stale J3 texts deleted, TX/RX/AUX labels fixed, OUT1..7. ERC unchanged (2 cosmetic), panel DRC 0/0; netlist diff = intended changes only
L4349: ee81601 Boards as hand-reworked by the instructor 2026-09-18 (Decision #66): three 2x20 links re-placed, jumpers -> headers, TCXO removed, 16 SMA; layout and routing in progress; review in the course repo notes
L4350: Bash
L4351: IN
L4352: cd /c/Users/Liang/AppData/Local/Temp/claude/audit-physics && cat > fw.js <<'EOF'
L4353: const fs=require("fs"); const N=require("C:/Users/Liang/tigp-2026/nmr-instrument/simulator/physics.js");
L4354: N.MAPS.tube=JSON.parse(fs.readFileSync("C:/Users/Liang/tigp-2026/nmr-instrument/simulator/m/fieldmap-tube.json"));
L4355: for (const T of [0.1,0.2,0.4,0.8]) { N.P.tAcq=T; const t0=Date.now(); const s=N.setup({sample:"tube",fTx:89400,b0I:1.5,tau:417,earthPar:0,earthPerp:0,nAvg:1,seed:3});
L4356:  console.log("tAcq",T,"FWHM",s.fwhm,"Hz  (1.207/T =",(1.207/(T-0.0012)).toFixed(1),") setup ms",Date.now()-t0); }
L4357: EOF
L4358: node fw.js
L4359: 
L4360: OUT
L4361: tAcq 0.1 FWHM 12 Hz  (1.207/T = 12.2 ) setup ms 101
L4362: tAcq 0.2 FWHM 6 Hz  (1.207/T = 6.1 ) setup ms 169
L4363: tAcq 0.4 FWHM 3 Hz  (1.207/T = 3.0 ) setup ms 269
L4364: tAcq 0.8 FWHM 1 Hz  (1.207/T = 1.5 ) setup ms 567
L4365: Bash
L4366: IN
L4367: S=/c/Users/Liang/AppData/Local/Temp/claude/c--Users-Liang-tigp-2026/a1274a3c-ba83-4c3b-98af-0f75dbaec45f/scratchpad; $S/nl net 'Net-(J3-Pin_1)' 'Net-(J3-Pin_3)' LNA_FB1; cd /c/Users/Liang/tigp-2026/class-board-2026/hardware; grep -n "J3\b\|pin 1 tied\|R712" sheets/nmr_rx.kicad_sch | grep -i "text" | cut -c1-300 | head; grep -n "Decision #73\|## #73\|#73" docs/design-decisions.md | head -3; git log -1 --format=%H%n%s 147f9cc | head -2
L4368: 
L4369: OUT
L4370: Net-(J3-Pin_1) [('J3', '1', 'Pin_1_1', 'C2937625_-_Conn_01x03'), ('R712', '2', None, '10.0k')]
L4371: Net-(J3-Pin_3) [('J3', '3', 'Pin_3_3', 'C2937625_-_Conn_01x03'), ('R714', '2', None, '1.00k')]
L4372: /nmr_rx/LNA_FB1 [('J3', '2', 'Pin_2_2', 'C2937625_-_Conn_01x03'), ('R713', '1', None, '100'), ('U703', '2', '-_2', 'OPA1656IDR')]
L4373: 7303:	(text "Stage 1: G = 1 + R712/R713 \n= 1 + 10 000/100 = 101"
L4374: 7336:	(text "2026-10-01: R712 (10k) is permanent - J3 pin 1 is tied to pin 2 (LNA_FB1); a shunt on J3 2-3 adds R714 (1k) in parallel (gain 101 -> 10.1). Before this change stage 1 had no feedback without a shunt."
L4375: 7491:	(text "JP702: stage-1 feedback select. 1-2 bridged (default) = R712, \nG = 101; cut and bridge 2-3 = R714, G = 11."
L4376: 147f9cc27763cbe17993390aaddf63626905bbc2
L4377: hardware: instructor 2026-10-01 saves synced (one GND net on both boards, PCB updated, R951-R958, headers DNP per Decision #73) + nmr_tx R808 -> TX_VMID, C813 removed, R805/R806 10 k (review B2)
L4378: Bash
L4379: IN
L4380: cd /c/Users/Liang/tigp-2026/class-board-2026; git status --short | head; git branch --show-current; git log -1 --format='%h %ci %s' | cut -c1-120; grep -n "#73" hardware/docs/*.md | cut -c1-300 | head -5
L4381: 
L4382: OUT
L4383: w1-yi-tsai
L4384: da56d2b 2026-10-03 00:34:13 +0800 Project 3 (Yi-Tsai): keep only the course hand-in here; the project lives in nmr-instr
L4385: Grep "(?i)orthogonal|crossed coil|crossed-coil|tee|two-coil|separate (TX|transmit|receive)|probe coil" (in C:\Users\Liang\tigp-2026\class-board-2026, glob: {hardware/docs/*.md,firmware/*.md,workbook/**/*.md,docs/references.md,hardware/README.md})
L4386: 1 line of output
L4387: SubagentHandback
L4388: IN
L4389: {
L4390:   "message": "## Firmware audit: class-board-2026 (branch w1-yi-tsai), NMR path\n\nEverything was read-only. I built both environments in a copy under `C:\\Users\\Liang\\AppData\\Local\\Temp\\claude\\audit-firmware\\fw\\` and changed nothing in the repo. Paths below are relative to `class-board-2026/`. Anything marked **[est]** or **[analysis]** has not been measured on hardware; no hardware run is recorded anywhere.\n\n### 1. How one scan runs today\n- **Task:** `xTaskCreatePinnedToCore(\"nmrseq\", stack 12288, priority 5, core 1)` (`Sequencer.cpp:47-49, 235`). It sleeps on `ulTaskNotifyTake` (`:249`) until `start()` (`:254-273`) calls `xTaskNotifyGive`. No timer interrupt and no ISR is used anywhere in the NMR path.\n- **Timing primitive:** `waitUntil()` (`Sequencer.cpp:71-77`) polls `esp_timer_get_time()`. It busy-spins below 1.5 ms and calls `vTaskDelay` above that.\n- **Set preparation** (`prepareHardware`, `:294-312`), once per scan set over I2C:\n  - Si5351 CLK0 = 50 MHz with a PLLA reset.\n  - `setLo` (`:314-321`): CLK1 = 4·f_lo, PLLB reset, Johnson-counter /CLR pulse through two TCA9535 I2C writes (`Tca9535.cpp:117-122`).\n  - DDS: RESET, FREQ0, PHASE0 = 0, PHASE1 = 180, RESET cleared.\n- **One scan** (`runOneScan`, `:386-500`):\n  1. Optional polarize: digitalWrite FET/H-bridge, then `waitMs`.\n  2. Phase: `dds.setPhase(0, φ)` and `setPhase(1, φ+90)`, PSEL = 0. Each is an SPI write that takes the SPI mutex (`:414-416`).\n  3. RX_BLANK low, wait `t_blank_pre_us` (`:419-420`).\n  4. Pulse: `on = esp_timer_get_time(); digitalWrite(TX_EN, HIGH); waitUntil(on + t90); digitalWrite(TX_EN, LOW)` (`:427-430`). This is a software-timed gate.\n  5. Echo only: `waitUntil(pulseEnd + tau)`, then `dds.selectPhase(true)` (SPI write under the mutex), then the 180° gate (`:436-451`).\n  6. Wait `t_dead_us`, unblank (`:456-457`). Wait `t_acq_start_us`, take `spibus::Guard g(200)` (`:472`), then `adc.burst()` (`:478`).\n  7. Blank again, `readFlags()` (`:489-490`). This is a no-op on v0.7 because `EXP_BIT_IFLAG/TFLAG = -1` (`pins.h:96-97`).\n- **ADC pacing** (`Ads8688.cpp:163-225`):\n  - Reprograms AUTO_SEQ (an extra SPI transaction), opens one Arduino `SPI.beginTransaction`, sends AUTO_RST.\n  - Per sample: `paceUntil(t0 + s·period)` busy-poll, then per channel CS low by register write, blocking `SPI.transfer32(NO_OP)`, CS high, flip the top bit, store to PSRAM.\n  - If it falls behind it catches up back-to-back with no overrun flag. It reports only the average `achieved_hz` (`:220-223`).\n- **Buffers:** `heap_caps_malloc(MALLOC_CAP_SPIRAM)` at `config` time, grow-only (`Sequencer.cpp:95-155`). Defaults: raw 800 kB, frame 400 kB, FFT 2×64 kB. Nothing is allocated per scan in the sequencer.\n- **DSP per scan** (`processScan`, `:502-539`, in `Dsp.cpp`):\n  - DC offset: mean of the last 10 % of the raw record if `t_acq_ms ≥ 1000`, else the whole record (`Dsp.cpp:36-40`).\n  - Boxcar decimation, which also does code-to-volts (`:42-61`).\n  - **No digital mixing:** the record stays at the IF.\n  - CYCLOPS: rotate by −φ (`:63-74`), φ = 90·(s mod 4) (`Sequencer.cpp:573`).\n  - Running mean in the frame payload under `frameLock_` (`:522-531`).\n  - Status-only spectrum `dsp::analyse` (`:536`): first ≤16384 samples, Hann window, radix-2 FFT, parabolic peak, median/1.17741 noise (`Dsp.cpp:137-212`).\n- **Network:**\n  - The sequencer sets `recordReady_`. The main loop's `NmrBlock::loop` calls `consumeRecord` → `ws.binaryAll` (`NmrBlock.cpp:86-91`, `main.cpp:74-78`). That is the whole averaged record, a 28-byte header plus n×8 bytes (400 kB at defaults), after **every** scan.\n  - JSON status goes out at 20 Hz. `get_record` resends the last record.\n  - Header `block_id` is hard-coded to 9 (`Sequencer.cpp:547`); nothing reads it.\n\n### 2. ADS8688 driver compared with the docs\n**What the code does:** Arduino `SPI` (the global SPIClass on SPI2), `SPISettings(17 MHz, MSBFIRST, SPI_MODE1)` (`Ads8688.cpp:34, 181`), one 32-bit `transfer32` per conversion, CS by GPIO register writes (`:40-41`).\n\n**Discrepancies:**\n\n| # | Doc / comment (quote) | Code |\n|---|---|---|\n| 1 | NMR-FIRMWARE.md:139 \"Uses `spi_device_polling_transmit` on a dedicated device handle at 17 MHz\" | Arduino `SPI.transfer32` on the shared global object, no ESP-IDF device handle (`Ads8688.cpp:181-200`). |\n| 2 | NMR-FIRMWARE.md:133 `begin()` \"…NO_OP, AUTO_RST\" | `begin` sends 2×NO_OP, 8 range writes and an AUTO_SEQ write. No AUTO_RST; that happens in `burst` (`:94-106, 185`). |\n| 3 | NMR-FIRMWARE.md:138 \"as fast as the loop allows … returns samples per channel achieved\" | Paced to `rate_hz` and always returns `n_per_channel` (`:176, 225`). |\n| 4 | Ads8688.h:33 \"17 MHz\" | **[est]** The ESP32 APB divider gives 80/5 = **16 MHz** effective. |\n| 5 | NMR-FIRMWARE.md:192 \"busy-waits inside a `portDISABLE_INTERRUPTS()`-free critical region no longer than the pulse itself\" | There is no critical region at all. The task spins for the whole acquisition (up to 4 s) at priority 5. |\n| 6 | NMR-FIRMWARE.md:179 \"priority high\"; Sequencer.h:13-14 \"at priority 5 on core 1 nothing here gets preempted except by interrupts\" | False. sdkconfig has `CONFIG_ARDUINO_EVENT_RUNNING_CORE 1` (arduino_events task, priority about 19). AsyncTCP is **priority 10, unpinned** (`AsyncTCP.h:37,50`). Both can preempt it. |\n| 7 | Sequencer.cpp:410-411 \"the PSEL bit, about 2 us of SPI\" | The write first takes the SPI mutex (`Ad9834.cpp:41`, Guard 50 ms), then beginTransaction and digitalWrite FSYNC. **[est]** 5–15 µs normally, up to 50 ms worst case. |\n| 8 | Sequencer.cpp:571 \"the app offers multiples of four\" (n_avg) | `nmr.js:77` uses `step=\"1\"`. |\n| 9 | Si5351.cpp:33-35 \"well under a millihertz\" | **[analysis]** About 9 mHz at CLK1 and about 2.2 mHz at the LO (23.8 Hz PLL step / (668·4) / 4). Harmless, but the comment is wrong. |\n| 10 | Ad9834.cpp:82 sets PHASE1 = 90; Sequencer.cpp:309 sets 180; NMR-FIRMWARE §3.7 says 180, then each scan overwrites it with φ+90 | Three different claims. |\n\n**Per-sample cost and maximum rate [est]:**\n- One 32-bit frame at 16 MHz is 2.0 µs. Arduino `spiTransferLongNL` overhead is about 0.5–1 µs. So one channel costs about 2.7–3.2 µs and a pair about 6–7 µs, plus about 0.3 µs for `esp_timer_get_time`.\n- That gives roughly **140–165 kS/s per channel sustained** for 2 channels.\n- The default 100 kS/s (10 µs budget) is achievable. The accepted maximum of 250 kS/s (`Sequencer.cpp:176`) is not.\n- When the rate is not met, the header still says `cfg.rate_hz/decim` (`Sequencer.h:81`, `:551`), so **the frequency axis is silently scaled wrong**. Only the status `rate_hz` shows the achieved value.\n- **VERIFY:** CS-high time between back-to-back frames is only tens of ns (`:197-199`). Check this against the ADS8688 CS-high/conversion timing and the AUTO_RST data latency.\n\n### 3. AD9834 and Si5351\n- **AD9834** (`Ad9834.cpp`):\n  - SPI mode 2 at 10 MHz (exact: 80/8), FSYNC through digitalWrite. Every word takes the mutex and opens its own transaction.\n  - Control word: B28 = 1, PIN/SW = 0.\n  - Frequency: control word, then FREQ0 LSB `0x4000|w&0x3FFF`, then MSB (`:85-107`). Resolution 50 MHz/2²⁸ = **0.186 Hz/LSB**.\n  - Phase: `0xC000/0xE000 | round(deg·4096/360)`, which is **0.088°/LSB** (`:109-120`).\n  - PSEL is a control-word bit (`:127-130`).\n  - **Phase switching inside a sequence works** with 2 registers via PSEL: echo already does it, and CYCLOPS sets the phase per scan. It costs one locked SPI write each time.\n  - Faster, deterministic switching would need PIN/SW = 1 and GPIO42 (`PIN_DDS_PSEL`). That loses the RESET and SLEEP bits, because those pins are tied low.\n- **Si5351** (`Si5351.cpp`), 25 MHz crystal, I2C at 400 kHz:\n  - CLK0: integer search gives PLLA 900 MHz / 18 = 50 MHz exact (`:147-161`).\n  - CLK1: R-divider doubling up to ≥1 MHz, largest even integer MS, fractional PLLB with denominator 1048575 (`:197-238`).\n  - The register encoding matches AN619. Control bytes 0x4F / 0x6F are correct.\n  - Bug: if `setClk1` fails (f_lo below about 1.3 kHz), `config` does not check the return value. `actualLo()` then falls back to the *requested* value (`NmrBlock.cpp:39-42, 160`).\n- **Core coherence problem [analysis, high impact]:**\n  - TX (DDS on PLLA) and LO (PLLB, plus a Johnson counter cleared by I2C once per set) free-run at different frequencies. The demodulated IF phase is therefore set by **absolute time** modulo 1/f_IF (185 µs).\n  - Nothing ties the pulse or the first ADC sample to that beat. Scan start comes from `vTaskDelay`/`esp_timer` on the ESP32's own crystal.\n  - **Each scan's record should carry a random phase, so coherent averaging and CYCLOPS cannot work on hardware.**\n  - SIM hides this: `simBurst` starts every record at phase φ_pulse (`Sequencer.cpp:627-629`).\n  - The redesign needs a hardware-synchronised start (gate triggered from a TX/LO-derived edge, a reference channel, or a homodyne LO). **VERIFY first on hardware.**\n\n### 4. Hard-real-time hazards\n- **Software TX gate:** if anything preempts between `digitalWrite HIGH` and `LOW`, the transmitter stays on for the length of that preemption, possibly milliseconds. AsyncTCP (prio 10), arduino_events (core 1) and ISRs can all do this. I_FLAG/T_FLAG are not connected, so nothing catches an over-pulse. The bench `pulse` command does the same on the **loop task at prio 1** (`NmrBlock.cpp:189-191`, `Sequencer.cpp:343-357`), which is worse.\n- **Mutex waits inside the sequence:** `spibus::Guard(200)` at acquisition start (`:472`), and the DDS Guard(50) inside tau for echo. b1's `readAll(0)` can hold the bus when the sequencer preempts it. **[est]** About 50–100 µs delay with priority inheritance.\n- **Sample-time jitter:** FreeRTOS tick (1 kHz) and other ISRs on core 1, plus higher-priority tasks. Late samples are taken back-to-back with no detection. Flash writes stall both cores' cache: LittleFS alarm saves (`AlarmEngine.cpp:143`) and OTA, neither refused during a scan.\n- **No heap, logging, JSON, String or WiFi** in the pulse or acquisition path. The 400 kB `ws.binaryAll` copy runs under `frameLock_` on the main task. `processScan` waits on it with `portMAX_DELAY` (`:522`), which jitters the repetition time but not the pulse.\n- **Loop task starved:** the loop task shares core 1 and is blocked for the whole 2–4 s spin, so the status broadcast stalls every scan. The CPU1 idle task is not watchdogged (sdkconfig only checks CPU0), so it does not crash.\n- **b1 `set_range`** is not refused during a scan. It can change the AI7/AI8 scaling between scans of an average (`InputsBlock.cpp:57-69`).\n- **Validation gaps:** `t_acq_start_us < t_dead_us` is accepted (sampling while still blanked). `status()` reads `spec_` non-atomically.\n\n### 5. Host side\n- **instrument.py:**\n  - `nmr` (`:323-369`): sends only f_tx, f_lo, sequence, n_avg; polls status; calls `get_record`.\n  - **Bug:** `next_binary` (`:104-118`) returns the *oldest* parked kind-3 frame from the `deque(maxlen=8)` (`:82`). Per-scan frames are parked while waiting, so the CLI typically returns the **scan-1 record**, not the final average.\n  - `nmr_spectrum` (`:287-302`): `np.hanning(n)` over the **entire** record (50 000 pts at defaults), no zero-padding, scale `2/sum(w)`.\n  - **[est]** For T2* = 0.4 s over 2 s, a full Hann window gives about **10 dB less SNR** than a matched exponential (relative 22 vs 71). Firmware and JS window only the first 0.655 s and lose about 3 dB.\n  - `nmr_peak`: 2 Hz guard, `skip = n/100`, `/1.177`, no interpolation. CSV time starts at the first sample, not the pulse.\n- **nmr.js:** its own radix-2 FFT (`:266-306`), Hann with `(nUse-1)` (`:321`), `MAX_FFT = 16384` (`:37`), scale `2/wsum` (`:329`), guard `max(2, 2/df)` bins, `skip = nfft/100`, `/1.177`. It exposes only 8 settings, with defaults duplicated (`:26-35`).\n- **Three different spectrum implementations:**\n  - Firmware: periodic Hann, `1/(sumW·√2)` scaling (V rms per quadrature), skirt `nfft/64+4`, parabolic peak.\n  - JS: symmetric Hann, `2/sum`, 16k points.\n  - Python: symmetric Hann, `2/sum`, full record.\n  - `2/sum` is the real-signal convention, so peak amplitudes differ by 2√2 (9 dB) between the board and the clients, and SNRs differ because of the window lengths.\n- **Four simulators:** `simBurst`, the `Ads8688` SIM burst (`:204-211`), `dev-nmr.html:39-105`, and the doc.\n\n### 6. Hard-coded constants (value, file:line; duplicates noted)\n\n| Constant | Value | Locations |\n|---|---|---|\n| f_tx | 89400 Hz | Sequencer.h:35, :53 (sim_larmor); instrument.py:230; nmr.js:27; dev-nmr.html:45; NMR-FIRMWARE.md:169; PROTOCOL.md |\n| f_lo | 84000 Hz | Sequencer.h:36; instrument.py:230; nmr.js:28; dev-nmr.html:45 |\n| IF | 5400 Hz | Ads8688.cpp:209 (sim); dev-nmr.html:39; Dsp.h:39 (comment) |\n| t90 / t180 | 417 / 834 µs | Sequencer.h:38-39; nmr.js:30, :91 |\n| tau | 20 000 µs | Sequencer.h:40 |\n| t_blank_pre / t_dead / t_acq_start | 20 / 1000 / 1200 µs | Sequencer.h:41-43 |\n| t_acq | 2000 ms (max 4000) | Sequencer.h:44, Sequencer.cpp:175; nmr.js:31, :76 (min 10 vs firmware min 1) |\n| rate_hz | 100 k (limits 1k–250k) | Sequencer.h:45, Sequencer.cpp:176 |\n| decim | 4 (1–1024) | Sequencer.h:46, Sequencer.cpp:177 |\n| n_avg | 1 (≤256) | Sequencer.h:47, Sequencer.cpp:178; instrument.py:325; nmr.js:77 |\n| t_repeat | 3000 ms | Sequencer.h:49 |\n| polarize settle | 5 ms | Sequencer.h:51 |\n| pulse cmd | 1–5000 µs | NmrBlock.cpp:187; nmr.js:91 |\n| Buffer caps | 1e6/ch; 131072; FFT 16384; margin 512 kB; chunk 256 | Sequencer.cpp:39-45; nmr.js:37 (16384 duplicated) |\n| Task | prio 5, core 1, stack 12288 | Sequencer.cpp:47-49 |\n| DDS MCLK | 50 MHz | Sequencer.cpp:298; NmrBlock.cpp:70-71; Ad9834.h:34, :53; Ad9834.cpp:61 |\n| SPI clocks | ADC 17 MHz; DDS 10 MHz | Ads8688.cpp:34; Ad9834.cpp:24 |\n| I2C / crystal | 400 kHz; 25 MHz | Si5351.cpp:43; Si5351.h:37 |\n| VCO / denominator | 600–900 MHz; 1048575 | Si5351.cpp:30-36 |\n| ADC ranges | AIN2/3 = ±5.12 V | Ads8688.h:68 |\n| Sim signal | 18 mV, T2* 0.4 s, 3 mV noise, 2 mV 50 Hz hum, offsets 5/−4 mV | Sequencer.cpp:57-63; dev-nmr.html:41-42; Ads8688.cpp:205 (0.4 again) |\n| Rayleigh median | 1.17741 | Dsp.cpp:19; instrument.py:318; nmr.js:361 |\n| DC guard | 2 bins / 2 Hz / max(2, 2/df) bins | Dsp.cpp:23; instrument.py:305; nmr.js:342 |\n| DC tail | last 10 % if ≥1000 ms | Dsp.cpp:36-40 |\n| Status rate | 50 ms | main.cpp:52 |\n\n### 7. Build and tests\n- `pio run -e esp32s3-sim` **succeeded**, 0 warnings: RAM 15.6 % (51 208 / 327 680 B), Flash 14.4 % (941 193 / 6 553 600 B).\n- I also built `esp32s3` (hardware): succeeded, 0 warnings, RAM 15.7 % (51 600 B), Flash 14.8 % (966 721 B).\n- Platform espressif32 7.1.2, Arduino core 2.0.17.\n- CI (`.github/workflows/build.yml`): build both envs, `buildfs`, and `ruff check` / `format --check` on `host/`. **There are no unit tests.** No PC test for `Dsp.cpp` exists, even though `Dsp.h:5-7` says it was designed for one. Nothing has run on hardware.\n\n### 8. Classification and known problems\n\n| Feature | Verdict | Why |\n|---|---|---|\n| Dsp decimate/rotate/mean/FFT (pure functions) | RETAIN + test | Clean and allocation-free; needs PC unit tests and a matched or half window. |\n| Grow-only PSRAM buffers at config | RETAIN | Sound. |\n| Record-in-frame, main-task send | RETAIN, change cadence | Per-scan 400 kB broadcast is heavy; send decimated or less often. |\n| Si5351 driver | RETAIN / VERIFY | AN619-correct; check the setClk1 return; VERIFY on the board. |\n| AD9834 driver | RETAIN / VERIFY | Correct sequences; take the mutex out of the timed path; consider PSEL by GPIO. |\n| Software TX gate (digitalWrite + spin) | REIMPLEMENT | Preemption can over-pulse; use RMT/MCPWM/GPTimer hardware one-shot sequencing. |\n| ADC burst (Arduino SPI, esp_timer polling) | REIMPLEMENT | Jitter, silent rate shortfall, 250k unreachable; use a hardware-timed trigger + SPI DMA (IDF `spi_device` queue), with overrun detection. |\n| TX/LO/acquisition phase synchronisation | REIMPLEMENT (missing) | Averaging/CYCLOPS are incoherent without it [analysis]. |\n| CYCLOPS sign, IF sign, Q-before-I order | VERIFY | Depends on mixer and counter wiring. |\n| I_FLAG/T_FLAG handling | VERIFY / REIMPLEMENT | Dead code on v0.7; needs hardware wiring for TX safety. |\n| SPI mutex shared with b1/b3 | REIMPLEMENT | No waits in timed sections; lock the bus for the whole set; refuse b1 `set_range` during a scan. |\n| Three spectrum implementations | REMOVE duplicates | One reference (Python or firmware), with consistent scaling and window. |\n| Four simulators | REMOVE duplicates | One physics model; it must include the absolute-time beat phase. |\n| `pulse` command on the loop task | REIMPLEMENT | Same over-pulse hazard at priority 1. |\n| instrument.py `next_binary` | REIMPLEMENT | Returns a stale record. |\n| `block_id = 9` hard-coded | REMOVE / fix | Unused and inconsistent with the registry. |\n\nOther problems with evidence: header rate ignores the achieved rate (`Sequencer.h:81`); `t_acq_start < t_dead` accepted (`Sequencer.cpp:160-219`); n_avg multiples of 4 not enforced (`nmr.js:77`); board `larmor_hz` uses the requested f_lo, not the actual (`NmrBlock.cpp:286`).\n"
L4391: }
L4392: OUT
L4393: {"success":true,"message":"Report delivered to your caller."}
L4394: 
L4395: SubagentHandback
L4396: IN
L4397: {
L4398:   "message": "## NMR physics audit: nmr-instrument @0914edb and class-board-2026 w1-yi-tsai @da56d2b (read-only)\n\n**Main findings**\n- The field maps are sound and can serve as golden data. I re-ran the Biot–Savart part of `nmr_exact.wls` at 5 voxels and it reproduces `fieldmap-tube.json` (df, b1, phi) to every printed digit.\n- `physics.js` reproduces its README table exactly. Its Bloch rotation and precession sign are correct (checked against an RK4 integration of dM/dt = γM×B).\n- **The reference script `nmr_exact.wls` has a handedness bug.** The SpinDynamica pulse rotates about +H, but the free precession afterwards uses e^{-iΩt}. These are opposite senses.\n  - Evidence: if I flip `physics.js`'s pulse axis to match SpinDynamica, its T2* moves from 79.88 to exactly 80.52 ms (tube) and from 40.96 to exactly 41.52 ms (bottle). Those are the SpinDynamica numbers.\n  - So the 0.6 ms \"agreement\" gap in the README is this convention mismatch, not numerical error. `physics.js` is the self-consistent one.\n- **The \"FWHM 6 Hz\" linewidth is not physical.** It is the spectral width set by the 0.2 s record (rectangular window, 1.207/T). With the exact tube map, record lengths of 0.1 / 0.2 / 0.4 / 0.8 s give 12 / 6 / 3 / 1 Hz. Do not use it as golden data.\n- **Three models put the line at different frequencies for the same 1.5 A:**\n\n| Model | Line at 1.5 A |\n|---|---|\n| `physics.js` approximate fields (B0nom = 89400/γ̄ fixed, `physics.js:20`) | 89 400 Hz |\n| Mathematica, finite cross-section winding (2.10347 mT) | 89 560 Hz |\n| `spectrum.py`, thin-wire Helmholtz with N = 312 (2.10407 mT, `spectrum.py:74-75`) | 89 585 Hz |\n\n  - The README's \"thin-wire formula 2.0997 mT\" (`README.md:48`, `nmr_exact.wls:67`) is wrong. 2.0997 mT is the design target before N was rounded up from 311.36 to 312. Thin-wire with 312 turns gives 2.10407 mT.\n  - The `probe.scad:296` echo prints the target field, not the field the coils produce.\n  - The \"retune to the tank\" current (`instrument.scad:107`; the `test-physics` \"1.484 A\" case) assumes the line is at 89 400 Hz. With the exact field it should be about 1.5×88469/89560 ≈ **1.4817 A** (estimate).\n- **The four models do not agree on the signal chain:**\n\n| Model | Signal | T2* | Gain | Noise |\n|---|---|---|---|---|\n| Firmware SIM | \"20 µV at coil\", 18 mV at ADC | 0.4 s | ×900 | 3 mV uniform |\n| `physics.js` | 0.90 µV emf, 8.8 µV at tank, about 0.2 V at ADC | 72–80 ms | ×25 500 | 49 mV rms |\n| `spectrum.py` | firmware SIM constants (0.018 / 0.003 / 0.002 / DC) | intrinsic T2 = 2 s, plus 4th-order field spread | — | — |\n\n- **`spectrum.py` uses a different sample model:**\n  - It uses r = 15 mm, the tube's outer radius (`spectrum.py:87`); `physics.js` and Mathematica use 14 mm.\n  - It keeps only x from −50 to +25 mm, the water inside the winding. The others use −58 to +45 mm.\n  - So its field spread is 193 Hz, against 298 Hz in Mathematica.\n  - Its \"decay\" T2* (1.03 s, from sliding-window peak height) is a different quantity from `physics.js`'s 1/e envelope T2*.\n- **`nmr_exact.wls` cannot run in full here.** SpinDynamica is not installed (no `SPINDYNAMICA` variable, no `sd371` folder, none under the user profile or the Wolfram install). The Biot–Savart part runs at about 0.03 s per voxel, so a full field map takes about 2 min (estimate). The README says about 5 min per run including SpinDynamica.\n\n## 1. The models\n\n**`simulator/physics.js`** (SI units; M in A/m; emf in V)\n- **Field, approximate mode:** Helmholtz 4th-order term −1.152(y⁴−3y²ρ²+⅜ρ⁴)/R⁴, with y along the pair axis (L56-62). Earth's field is added along B0 and in quadrature across it.\n- **Field, exact mode:** from the maps, B = (89400+df)/γ̄·(I/1.5) + B_earth (L96-98).\n- **B1, approximate mode:** on-axis finite solenoid μ0N/L·½[(x+h)/√… − (x−h)/√…] (L32-35, L101). It ignores the radial variation and the real two-layer winding, which is why it gives t90 = 451 µs.\n- **Pulse:** the rotating component is half the linear field (L104). The rotation is exact Rodrigues about −B_eff in the f_tx frame, including the B1 direction φ (L64-70, L103-108).\n- **Coil current:** iTx = 7.95/|6.7 + jωL| (L91). It ignores R813 (4.7 Ω) and the tank capacitor on the shared coil.\n- **Magnetization:** Curie law M0 = Nγ²ħ²B/(4kT) (L107).\n- **Pickup:** reciprocity, emf = ω·B1⊥/I·M⊥·dV (L120). It uses ω_tx rather than the local Larmor frequency (about 0.2 % error).\n- **Free precession:** M⊥·e^{−iΔωt}·e^{−t/T2}, with received phase e^{−iφ} (L122-131).\n- **Relaxation:** T1 recovery appears only in `state()` (L196). Averaging uses a steady-state Mz from the centre voxel's flip, (1−E1)/(1−E1cosθ) (L111-114).\n- **Tank:** a scalar Lorentzian gain Q/√(1+(2QΔf/f0)²) at the line frequency (L136). No phase shift and no noise shaping.\n- **Detection:** the signal is conjugated so that a line above f_tx lands above the 5.4 kHz IF; I = Re, Q = Im of e^{+i2πf_IF t} (L142-143).\n- **Noise and blanking:** Gaussian, σ = 15.6 nV/√Hz·√15 kHz/√n per channel (L137). That is about 10 % above en·√(12.5 kHz) at 25 kS/s complex (estimate; needs checking). The first 1.2 ms are zeroed (L145).\n- **Line position:** phase slope over the first 1 ms (L177-185).\n- **Linewidth and spectrum:** naive DFTs (L156-160, L203-216).\n- **Not modelled:** spin echo, pulse ringdown, the tank's transient.\n\n**`mechanical/spectrum.py`**\n- Relative field offsets from the 4th-order Helmholtz term over a uniform disk sample (L89-100).\n- Signal amplitude scales as f² times the tank response (L133). `f_tank` defaults to f_tx, not 88 469 Hz (L70).\n- Lines are placed on 0.5 Hz FFT bins, then shifted by the t0 dead time and multiplied by e^{−t/T2} (L106-120).\n- Hum, noise and DC offsets are the firmware SIM constants (L118-120).\n- Voltage-drive heating: dT += I²R0(1+αdT)·t_rep/(m·c), with I = I_set/(1+αdT) (L123-136). This is self-consistent.\n- Its own `spectrum()` uses a half-Hann window with truncation (L146-163).\n- It reads `.scad` constants with a regex (L49-55).\n\n**`simulator/build/nmr_exact.wls`**\n- Exact single-loop Biot–Savart using elliptic integrals (L37-43).\n- B0 pair: 5×5 filaments per coil, 312 turns, R = 200 mm, cross-section 28×27 mm (L46-47).\n- Class coil: 222 turns at r = 20.225 mm plus 178 turns at r = 20.675 mm, 0.45 mm pitch, from x = −50 mm (L50-51).\n- B1⊥ and φ in a frame built from the local B0 (L70-76).\n- SpinDynamica pulse (L80-82), then FID with e^{−iΩt} (L97). This is the handedness inconsistency described above.\n- Same tank and FWHM definitions as `physics.js` (L101-107).\n- Voxel grid starts at x0+g/2 (L59), so it is off-centre: tube y and z run −12.75 to +12.25 mm; bottle y and z run −16 to +17 mm. As a result, tube volume is 55.55 mL against 55.88 analytic, and bottle is 121.77 mL against 119.3 (+2 %).\n\n**Firmware SIM (`Sequencer.cpp:51-63`, `:611-685`)**\n- A single complex exponential at the IF (sim_larmor − f_lo) with the scan phase, a fixed 18 mV amplitude, and e^{−t/0.4 s} starting at the first sample.\n- Uniform noise of 3 mV rms from an LCG, 2 mV of 50 Hz hum as a complex tone, and DC offsets.\n- Generated at the raw 100 kS/s and boxcar-decimated by 4 (`Sequencer.h:45-46`).\n- It ignores t90, flip angle, echo (`:436-451` waits but simulates nothing), field and tank.\n- The I/Q convention matches everywhere else: Larmor = f_lo + peak (`NmrBlock.cpp:286`, `instrument.py:290`).\n\n**I/Q sign:** all four models agree that a positive IF offset means a line above f_lo. None of them has been checked against the real mixer wiring.\n\n## 2. Analytic checks\n- **`test-physics.js`:** has no assertions; it only prints. In Node the field maps are never loaded, so it runs the approximate model. Default tube: emf 0.83 µV, t90 451 µs, T2* 72.4 ms, FWHM 6 Hz, about 0.4–0.6 s per case, 3.6 s in total.\n- **Helmholtz 4th order (numeric loop integration):**\n\n| Offset | Axial error | 1.152(s/R)⁴ | Radial error | ⅜·1.152(s/R)⁴ |\n|---|---|---|---|---|\n| 10 mm | −7.18e-6 | −7.20e-6 | −2.706e-6 | −2.700e-6 |\n| 30 mm | −5.69e-4 | −5.83e-4 | −2.23e-4 | −2.19e-4 |\n\n  The coefficients are correct. The 6th-order term adds about 2.5 % at 30 mm.\n- **Finite solenoid on axis:** numeric 4.65246e-3 T/A against analytic 4.65245e-3 at x = 0; it also matches at x = 40 and −55 mm.\n- **Two-layer coil centre:** my independent loop sum gives 5.029625e-3 T/A, identical to the map's `centre.b1`.\n- **Coil current and t90:** iTx = 5.59402 mA gives t90 = 417.38 µs. The long-solenoid formula gives 417.64 µs, so the workbook's 417 is the infinite-solenoid number and matches the exact value partly by coincidence. The approximate model gives 451.22 µs.\n- **Curie law:** M0 = 6.909e-6 A/m at 2.0997 mT and 293 K. The formula and N_H = 6.69e28 m⁻³ are correct.\n- **Bloch rotation:** Rodrigues and RK4 agree to 5 decimals at Δf = 0, +160 Hz, and −300 Hz with φ = 0.4. Example: Δf = 160 Hz, 417.38 µs, B1rot = 14.068 µT gives (0.26306, 0.96466, 0.01522).\n- **Precession sign:** at 100 Hz for 1 ms, M⊥ goes to e^{−i0.2π}, which is clockwise and correct for γ > 0.\n- **Hahn echo (90x–τ–180y–τ, Δf spread ±150 Hz):** hard pulses refocus to 1.0000. The real 14.07 µT B1 gives 0.968 at the echo (0.990 right after the 90°). This is my script, not a project feature.\n- **Relaxation:** T2 decay and the T1 recovery formula in `state()` are correct.\n\n## 3. Field maps\n- **Format:** JSON with `source`, `sample`, `grid_mm` (2.5 for the tube, 3 for the bottle), `B0_centre_mT_at_1.5A` (2.10347), `centre.b1` (T/A), and per voxel:\n  - `p`: position in mm, coil frame (x along the coil axis, y along B0);\n  - `df`: Hz offset from 89 400 at 1.5 A, no Earth field, rounded to 1 mHz;\n  - `b1`: coil field per amp perpendicular to the local B0, 6 significant figures;\n  - `phi`: direction in rad, rounded to 1e-4.\n- **Size:** 3555 voxels (tube) and 4510 (bottle). An `spindynamica` summary block is included.\n- **Ranges:** tube df −128.9 to +169.2 Hz, b1 1.56 to 5.11 mT/A, φ ±0.47 rad.\n- **How made:** `nmr_exact.wls`, then `compact.py`. Note that `compact.py:7` hardcodes iTx.\n- **Trust:** the Biot–Savart values are reproducible and correct. They are suitable as golden data for B0 and B1 at fixed points. Caveats:\n  - asymmetric, coarse grid;\n  - idealised winding (uniform 5×5 filaments; layer 2 from −50 to +30 mm per the winding note);\n  - the SpinDynamica summary fields T2star, flip and fwhm are not golden (see above).\n\n## 4. Constants (value, file:line)\n\n| Quantity | Values found | Status |\n|---|---|---|\n| γ̄ | 42.577e6 Hz/T: `nmr-params.scad:9`, `physics.js:12`, `wls:28` | consistent |\n| f_tx / f_lo | 89400 / 84000: `nmr-params:6-7`, `Sequencer.h:35-36`, `instrument.py:230`, `wls:30` | consistent |\n| B0 at 1.5 A | 2.0997 mT target (`physics.js:20`, `nmr-params:10`); 2.10407 thin-wire N = 312 (`spectrum.py:75`); 2.10347 exact (map) | **3 values** |\n| B0 pair | R = 200 mm, I = 1.5 A, N = 312 (computed, `probe.scad:224-232`), 28×27 mm (`probe.scad:228,233`; `wls:33`) | consistent; 10.33 Ω, 9.2 kg Cu |\n| Coil | 400 turns, 100 mm, wire 0.45 mm, former 40 mm (`probe.scad:48-52`); mean radius 20.45 mm (`physics.js:18`) vs 20.225/20.675 mm (`wls:50`) | consistent (mean vs layers) |\n| L, R, Q | 2.53 mH, 6.7 Ω, 10: `nmr-params:13-15`, `physics.js:18`, `wls:31` | consistent |\n| TX drive | 7.95 V pk → 5.594 mA | consistent |\n| Tank C / fTank | 1.2527 nF needed (`nmr-params:16`); fTank 88 469 Hz (`physics.js:21`, `wls:30`, computed in `instrument.scad:99`); `spectrum.py` defaults to 89 400 | **disagree** |\n| t90 | 417 µs (`nmr-params:26`, `Sequencer.h:38`, `wls:30`); 451 µs from `physics.js` approximate mode; t180 834 µs (`Sequencer.h:39`) | approximate mode is wrong |\n| Dead time / acquisition start | 1.0 / 1.2 ms (`Sequencer.h:42-43`); 1.2 ms used as blanking (`physics.js:22`, `spectrum.py` t0) | minor |\n| Record length | 2 s (`nmr-params:28`, `Sequencer.h:44`); 0.2 s in `physics.js:22`; 5000 samples in `wls:93` | disagree; this is what sets the 6 Hz FWHM |\n| Sample rate | 100 kS/s raw ÷ 4 = 25 kS/s | consistent |\n| T1 / T2 / TR | 2.5 / 2.0 / 3.0 s | consistent |\n| Firmware SIM T2* | 0.4 s (`Sequencer.cpp:58`) vs 80 ms modelled | **disagree** |\n| Noise / gain | 15.6 nV/√Hz, 15 kHz, ×25 500 (`physics.js:24-25`); 3 mV and ×900 (`Sequencer.cpp:52-59`) | **disagree** |\n| Sample geometry | r 14 mm, x −58..+25 mm plus 20 mm cone (`physics.js:39`, `wls:56`); r 15 mm, x −50..+25 mm (`spectrum.py:86-87`) | **disagree** |\n| Copper constants | α = 0.00393 /K, c = 385 J/(kg·K) | consistent |\n\n## 5. Performance\nNode timings with the exact maps:\n- `setup()` takes 160–180 ms. The hot loop is voxels × samples (3555 × 5000, `physics.js:122-131`).\n- The linewidth DFT is 801 frequencies × 2500 samples (L156-160).\n- `spectrum()` is a naive DFT, 400 frequencies × 4970 samples, about 80 ms (L203-216).\n- `state()` takes about 0.5 ms.\n- Cost scales linearly with record length: 567 ms at 0.8 s, so roughly 1.5–2 s at the firmware's 2 s record (estimate).\n- `spectrum.py` runs in 1.7 s for a sweep; `test-physics.js` in 3.6 s total.\n\n## 6. Classification\n\n| Feature | Verdict | Why |\n|---|---|---|\n| Rodrigues rotation about −B_eff, precession e^{−iΔωt} | RETAIN | Matches the ODE; correct handedness |\n| Curie M0, reciprocity emf, rotating B1 = ½ linear | RETAIN | Analytically correct |\n| Exact Biot–Savart field maps / elliptic loop kernel | RETAIN (port the kernel to C++) | Reproduced exactly; fast |\n| Approximate 4th-order Helmholtz and on-axis solenoid | REIMPLEMENT | B0nom ignores N = 312; B1 has no radial or two-layer model (451 vs 417 µs) |\n| Exact-mode voxel grid | REIMPLEMENT | Off-centre grid, ±2 % volume |\n| Scalar tank gain, no transient | REIMPLEMENT | Needs a complex response; noise not shaped |\n| Noise σ = en√bw | VERIFY | Bandwidth and decimation inconsistent (about 10 %) |\n| I/Q convention | VERIFY | Consistent in code, not checked against hardware |\n| Steady-state averaging from the centre voxel | VERIFY | Approximation; not SSFP-correct with T2 ≈ TR |\n| `nmr_exact.wls` SpinDynamica comparison | REIMPLEMENT | Handedness mismatch |\n| FWHM / \"linewidth\" output | REMOVE or redefine | Window-limited artifact |\n| Firmware SIM constants | REIMPLEMENT | Should come from the shared core (no echo, wrong T2*, wrong amplitude) |\n| `spectrum.py` physics layer | REIMPLEMENT on the shared core | Third line position and different sample model; keep the print/heating logic |\n| Coil-heating drift | RETAIN | Self-consistent |\n| `test-physics.js` | REIMPLEMENT as asserting tests | Currently print-only |\n\n**Golden reference values (provenance in brackets):**\n- **Analytic:**\n  - Helmholtz thin-wire, N = 312, I = 1.5 A, R = 0.2 m: 2.10407 mT.\n  - 4th-order coefficients 1.152 and 0.432.\n  - Finite solenoid, 400 turns, L = 0.1 m, a = 20.45 mm: 4.65245e-3 T/A at the centre.\n  - M0 = 6.9094e-6 A/m (N = 6.69e28 m⁻³, 2.09973 mT, 293 K).\n  - iTx = 5.59402 mA.\n- **Biot–Savart (Mathematica, independently confirmed):**\n  - B0 centre 2.1034711 mT at 1.5 A.\n  - B1 centre 5.029625e-3 T/A, giving t90 = 417.38 µs and B1rot = 14.068 µT.\n  - Voxel spot checks, as (position mm, df Hz, b1 T/A, φ rad): (−56.75, −12.75, −5.25) → 10.4631, 1.558114e-3, −0.20769; (5.75, −0.25, 4.75) → 159.5552, 4.966064e-3, −0.00833.\n- **Bloch:** the RK4 vectors above; Hahn refocusing 1.0000 with hard pulses.\n- **`physics.js`, exact maps, 89.4 kHz, 417 µs, seed 3:**\n\n| Sample | emf (µV) | Tank (µV) | T2* (ms) | Line (Hz) |\n|---|---|---|---|---|\n| Tube | 0.90215 | 8.766 | 79.88 | 89 559.5 |\n| Bottle | 1.64262 | 15.96 | 40.96 | 89 559.2 |\n\n  These are trustworthy for regression after the convention fix. Do not use the FWHM, the SpinDynamica T2* values, the SNR or the firmware SIM amplitudes as golden data.\n\n**Files** (all scratch output in `C:\\Users\\Liang\\AppData\\Local\\Temp\\claude\\audit-physics\\`; nothing in either repo was modified):\n- `checks.py`: Helmholtz, solenoid, Curie and coil-centre checks\n- `bloch.js`: rotation, precession sign and Hahn echo checks\n- `exact.js`: `physics.js` with the field maps loaded\n- `conv.js`, `physics_sdconv.js`: the handedness experiment\n- `fw.js`: FWHM against record length\n- `bs.wls`: Biot–Savart recompute of 5 map voxels\n"
L4399: }
L4400: OUT
L4401: {"success":true,"message":"Report delivered to your caller."}
L4402: 
L4403: SubagentHandback
L4404: IN
L4405: {
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

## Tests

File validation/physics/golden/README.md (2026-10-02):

# Golden reference data

| File | Provenance | Trusted quantities | Not trusted |
|---|---|---|---|
| `fieldmap-tube.json`, `fieldmap-bottle.json` | legacy `nmr_exact.wls` (Mathematica 13.3, exact single-loop Biot–Savart with elliptic integrals); the Milestone 0 audit recomputed sample voxels independently and matched every printed digit | voxel positions `p` [mm], `df` [Hz], `b1` (B1⊥ per amp) [T/A], `phi` [rad], `B0_centre_mT_at_1.5A`, `centre.b1` | the `spindynamica` block (T2*, flip, FWHM): handedness mismatch in the legacy script, and a record-length-limited FWHM (docs/audit.md) |

`df` is relative to the legacy constants in `legacy-constants.json` (γ̄ = 42.577 MHz/T unshielded and rounded,
f_tx = 89 400 Hz, I = 1.5 A). They are legacy values, kept only to interpret the golden data; the new implementation's
constants live in `design/instrument.yaml`.

Rounding of the stored values (the tolerance floor of any comparison): `df` 1 mHz, `b1` 6 significant figures,
`phi` 1e-4 rad.

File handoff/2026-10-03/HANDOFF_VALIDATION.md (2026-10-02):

# Handoff Package Validation

Scope: documents, metadata, links, source preservation and the read-only handoff diagnostic. **No NMR physics test, firmware build, hardware measurement or deployment was performed for this package.**

| Check | Result |
|---|---|
| missing-root error | PASS |
| unestablished empty tree | PASS |
| partial-v2 detection | PASS |
| complete-sentinel detection is explicitly unverified | PASS |
| probe leaves synthetic source unchanged | PASS |
| external symlink not read | PASS |
| actual supplied archive classified as legacy | PASS |
| actual extracted source and Git bytes unchanged | PASS |
| original source archive unchanged | PASS |
| all 160 source fingerprints still match | PASS |
| structured data parses | PASS |
| local Markdown links resolve | PASS |
| all bootstrap read-order files included | PASS |
| additive install layout only | PASS |
| no replacement .git or compiled payload | PASS |

The synthetic v2 fixtures test file-presence classification only; they are not recovered v2 source. The real supplied snapshot was correctly classified as `LEGACY_SNAPSHOT_ONLY`, with diagnostic exit code 3.

The original ZIP and all 160 extracted non-Git files were fingerprinted and unchanged. Byte fingerprints of the extracted Git data were also unchanged across the diagnostic run.

`evidence/handoff-package-checks.json` records the package checks. Actual instrument progress remains classified in `CURRENT_STATE.md` and requires live recovery and revalidation.

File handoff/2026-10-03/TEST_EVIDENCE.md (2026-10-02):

# Test and Build Evidence Ledger

## Status

All instrument results below are **TRANSCRIPT_REPORTED**. Handoff preparation did not rerun NMR builds, numerical validation or hardware tests. New results must identify actual source/config hashes.

| Evidence | Recorded result | Original transcript lines | Does not prove |
|---|---|---|---|
| M1 configuration | 12 tests passed | 5265–5272 | Recovered live inputs match that run |
| M2/M3 native summary | Bloch 26, field 29, DSP 15, pulse 31, simulation 14; 115 native checks reported | 8567–8572; 8614–8617 | Firmware build or hardware operation |
| M2/M3 Python | 15 passed after duplicate-constant fix | 8583–8616 | All subsequent changes passed |
| Golden maps | 3555 tube / 4510 bottle voxels; max df 5.48e-4 Hz; relative B1 2.80e-6 / 4.95e-6; phi 5.00e-5; 3 tests passed | 8558–8563 | Measured magnet field or complete model adequacy |
| WASM | 393 KiB module reported | 9061–9062 | Binary reflects later config changes |
| Native/WASM parity | One test passed; sampled ADC differences I=0, Q=0 LSB | 9034–9065 | Universal bitwise agreement for all inputs or processed outputs |
| Later config update | 12 config tests passed after 125 kS/s / decimation 5 and pin-map change | 9146–9207 | Fresh parity after that change or actual ADC rate |
| Backend planner | 20 checks passed; selected pulse/sim/DSP suites also passed | 9469–9478 | One fresh run of every earlier suite |
| Final firmware | Components written/registered; headers inspected | 10181–10746 | Complete build, link, flash or bench acquisition |

The parity test checks selected record slices and uses tolerances for processing/peaks. Its surrounding prose is stronger than the actual assertions. Do not generalize one test into universal exactness.

## Preserve the failed-test history

The M2/M3 command piped pytest through `tail`, masking the producer's failure status. The transcript records a commit despite `1 failed, 14 passed`. The author fixed duplicate constants, reran, and amended to `de1a13f` (L8565–8616).

Always capture each producer's actual exit code and complete logs. Do not use a successful pipe consumer, an empty grep result or “no tests found” as test success. Record skips distinctly; a skipped WASM test is not parity validation.

## Baseline commands after v2 source recovery

Inspect the real files first. These paths do not exist in the supplied main snapshot.

```powershell
py tools/gen_config.py --check
cmake -S . -B build -G Ninja
cmake --build build
ctest --test-dir build --output-on-failure
py -m pytest -q tests
```

Confirm CTest discovers the declared tests. If it does not, inspect `CMakeLists.txt` and execute the actual test binaries separately.

For parity, once dependencies and the build script are reviewed:

```powershell
py simulator/wasm/build.py
py -m pytest -q -rs tests/test_wasm_parity.py
```

For the new firmware, after integration is ready:

```powershell
pio run -d firmware -e esp32s3
```

No upload/flash command is authorized by these build instructions. On PowerShell, inspect `$LASTEXITCODE` immediately after each external command; on a shell using pipelines, preserve the producer's exit status rather than only the final filter's.

## Environment continuity

The transcript records Windows/Git Bash, Python 3.11, MinGW C++/CMake/Ninja, Node, Clang/WASI tooling and `espressif32@7.1.2`. Installed header output reports ESP-IDF major 6/minor 1 at L9946–9953. These are historical environment observations, not statements about the latest available software or the receiving machine.

Inspect versions, paths and lockfiles. Do not silently upgrade or assume a tool is installed because an old path exists in a report.

## Missing raw artifacts

The uploaded ZIP has no v2 `validation/`. Historical command output retained in this handoff is not the original compiler logs, KiCad JSON/netlists or hardware traces. Recover required raw evidence from the live tree/local audit folders; rerun targeted checks when it is unavailable.

## New evidence record

```text
Command:
Working directory:
Source HEAD and dirty state:
Config SHA-256:
Tool/compiler versions:
Time with timezone:
Exit code:
Executed / passed / failed / skipped:
Raw log path:
Evidence class:
Limitation:
```

Simulation validation, firmware loopback, TX/RX bench validation, probe calibration, FID detection and echo validation remain separate gates.

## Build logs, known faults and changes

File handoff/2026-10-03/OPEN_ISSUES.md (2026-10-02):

# Open Issues for Continuation

> This is a handoff issue register, not a fresh scientific/electrical audit. Issues derived from old agents remain historical until checked against the recovered source. Proposed owners are roles, not active agents. Nothing here is marked bench-validated.

| ID | Severity | Status | Issue |
|---|---|---|---|
| HANDOFF-001 | blocker | SOURCE_RECOVERY_REQUIRED | The uploaded archive lacks the v2 working tree |
| HANDOFF-002 | major | EVIDENCE_RECOVERY_REQUIRED | Raw v2 validation artifacts are absent from the ZIP |
| FW-RESUME-01 | blocker | TRANSCRIPT_REPORTED_WIP | Firmware main/control integration is the interrupted continuation area |
| FW-IQ-001 | major | TRANSCRIPT_REPORTED_PENDING | I/Q aperture-skew correction was announced but not shown completed |
| FW-ADC-001 | blocker | PROPOSED_NOT_BENCH_VALIDATED | I2S/DMA ADC framing needs protocol and timing verification |
| SYS-PHASE-001 | blocker | PROPOSED_NOT_BENCH_VALIDATED | TX/LO/acquisition phase-reference closure remains unmeasured |
| HW-TXR-001 | blocker | LEGACY_REPORTED_OPEN | Shared-coil transmit/receive isolation remains an instrument blocker |
| HW-B0-001 | blocker | LEGACY_REPORTED_OPEN | B0 current/field stability has not been experimentally closed |
| HW-SAFE-001 | critical | LEGACY_REPORTED_OPEN | Fault wiring, LNA feedback and power protection need source-specific closure |
| SIM-PARITY-001 | major | REVALIDATION_REQUIRED | WASM parity must be re-established after later config edits |
| DOCS-ADR-001 | major | AVAILABILITY_UNKNOWN | Referenced ADRs are not supplied as verified files |
| HW-INTEGRATION-001 | major | BOUNDARY_TO_DOCUMENT | Experimental successor firmware and course-source ownership need an explicit boundary |
| NMR-EVIDENCE-001 | blocker | NOT_EVIDENCED | Real FID/spectrum/echo validation is still not evidenced |

## HANDOFF-001 — The uploaded archive lacks the v2 working tree

**Basis:** Direct ZIP/Git inspection: main at 0914edb, no v2 ref or successor directories.

**Next action / closure:** Recover the live v2 tree and uncommitted firmware, or reconstruct missing source in isolation with provenance. Do not overwrite newer source.

**Evidence:** CURRENT_STATE.md; snapshot-manifest.json. **Suggested owner:** Recovery owner.

## HANDOFF-002 — Raw v2 validation artifacts are absent from the ZIP

**Basis:** The transcript reports saving outputs; the source snapshot has no validation tree.

**Next action / closure:** Recover raw logs/netlists or rerun the relevant checks. Preserve historical reports without promoting them.

**Evidence:** TRANSCRIPT L4575-L4597; evidence/legacy-*-audit.md. **Suggested owner:** Verification owner.

## FW-RESUME-01 — Firmware main/control integration is the interrupted continuation area

**Basis:** Gate engine, ADC and RF writes are recorded; next control-loop work was announced.

**Next action / closure:** Inspect live files for subsequent work, finish missing integration, and produce a complete build with raw exit status.

**Evidence:** TRANSCRIPT L10383-L10746. **Suggested owner:** Integration builder.

## FW-IQ-001 — I/Q aperture-skew correction was announced but not shown completed

**Basis:** Last ADC handback proposes a fractional-delay correction, with a prior estimate of about 7.8 degrees.

**Next action / closure:** Verify conversion/channel timing; implement shared correction once; test sign, phase, transients and replay.

**Evidence:** TRANSCRIPT L10584; NEXT_ACTIONS.md. **Suggested owner:** ADC/phase reviewer.

## FW-ADC-001 — I2S/DMA ADC framing needs protocol and timing verification

**Basis:** New streamer and 125 kS/s / decimation 5 config appear as source writes, not hardware throughput evidence.

**Next action / closure:** Verify ADC framing, startup latency, channel mapping, CS timing, loss detection and actual first-sample timing before accepting acquisition.

**Evidence:** TRANSCRIPT L9146-L9208; L10384-L10584. **Suggested owner:** ADC/phase reviewer.

## SYS-PHASE-001 — TX/LO/acquisition phase-reference closure remains unmeasured

**Basis:** Legacy audits raise coherence concerns; v2 proposes capture inputs labeled ECO-1.

**Next action / closure:** Confirm actual wiring and missing-input handling; validate timestamps and coherent known-tone acquisition before NMR averaging claims.

**Evidence:** evidence/legacy-firmware-audit.md; TRANSCRIPT L9182-L9184. **Suggested owner:** ADC/phase reviewer.

## HW-TXR-001 — Shared-coil transmit/receive isolation remains an instrument blocker

**Basis:** Historical electronics report describes separate TX/RX nets, clamp loading for a shared connection, and no isolating T/R switch.

**Next action / closure:** Check live board/source revision; validate a chosen topology and RX recovery. A calculated diode-drop parameter is not proof of applied hardware.

**Evidence:** evidence/legacy-electronics-audit.md; TRANSCRIPT L5111-L5146. **Suggested owner:** Hardware reviewer.

## HW-B0-001 — B0 current/field stability has not been experimentally closed

**Basis:** Historical report describes voltage-driven operation and absent B0 current sensing at its audited revision.

**Next action / closure:** Verify revised current-drive/sensing design, compliance and drift/noise evidence; do not substitute simulation for measurements.

**Evidence:** evidence/legacy-electronics-audit.md; evidence/legacy-physics-audit.md. **Suggested owner:** Hardware/physics reviewer.

## HW-SAFE-001 — Fault wiring, LNA feedback and power protection need source-specific closure

**Basis:** Later audit reports unwired PA flags, J3-dependent feedback and power-sequencing/protection concerns.

**Next action / closure:** Check actual connectivity and hardware revision; validate safe states before connecting/energizing the real chain. Do not inherit an automatic-abort claim.

**Evidence:** evidence/legacy-electronics-audit.md. **Suggested owner:** Hardware reviewer.

## SIM-PARITY-001 — WASM parity must be re-established after later config edits

**Basis:** One parity run precedes the 125 kS/s/decimation 5 and pin-map changes.

**Next action / closure:** Rebuild native and WASM from the same current sources/config; record passes, tolerances and skips.

**Evidence:** TRANSCRIPT L8996-L9065; L9146-L9208. **Suggested owner:** Verification owner.

## DOCS-ADR-001 — Referenced ADRs are not supplied as verified files

**Basis:** ADR identifiers appear in code/comments; no ADR directory is present in the archive.

**Next action / closure:** Find live ADRs; reconstruct missing rationale explicitly as retrospective records, never as fabricated historical approvals.

**Evidence:** DECISION_LOG.md; snapshot-manifest.json. **Suggested owner:** Continuity owner.

## HW-INTEGRATION-001 — Experimental successor firmware and course-source ownership need an explicit boundary

**Basis:** Archive README assigns real hardware/firmware to class-board; later v2 begins successor firmware in nmr-instrument.

**Next action / closure:** Document what is legacy-authoritative, experimental successor, and approved for promotion; do not overwrite the course repository.

**Evidence:** CURRENT_STATE.md; DECISION_LOG.md. **Suggested owner:** Systems owner.

## NMR-EVIDENCE-001 — Real FID/spectrum/echo validation is still not evidenced

**Basis:** Archive describes no measurements; later text contains software work and a USB-device observation, not an NMR dataset.

**Next action / closure:** Retain hardware and NMR gates; save raw records and controls when real tests become authorized and available.

**Evidence:** README.md in source archive; TRANSCRIPT L5049-L5063; TEST_EVIDENCE.md. **Suggested owner:** Independent verifier.

## Update rule

Preserve these initial statuses. Record live source/config identity and evidence when advancing an issue. A code commit can resolve an implementation defect without resolving the associated hardware-validation gate. Keep a new live register or carefully merge into an existing one; do not overwrite newer issue state.

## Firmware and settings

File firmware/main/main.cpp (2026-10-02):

// Firmware entry point. Builds the hardware map and a default experiment from the generated instrument config, then
// drives one experiment through the control state machine: configure -> arm -> run. Results are printed over the
// console. No flashing, energising or bench claim is made here; this is the software integration of the components.
#include <cmath>
#include <cstdio>

#include "esp_log.h"
#include "freertos/FreeRTOS.h"
#include "freertos/task.h"

#include "controller.hpp"
#include "instrument_config.hpp"
#include "pulse/compiler.hpp"

using namespace nmr::cfg;

namespace {
const char* TAG = "main";

constexpr uint8_t kSi5351Addr = 0x60;   // Si5351A default 7-bit I2C address (VERIFY against the board)

fw::Hardware make_hardware() {
    fw::Hardware hw{};
    hw.pin_tx_gate = static_cast<int>(PINS_TX_EN);
    hw.pin_rx_open = static_cast<int>(PINS_RX_BLANK);
    hw.pin_phase_sel = static_cast<int>(PINS_DDS_PSEL);
    hw.pin_dds_sign = static_cast<int>(PINS_CAP_DDS_SIGN);
    hw.pin_lo_i = static_cast<int>(PINS_CAP_LO_I);
    hw.pin_capture_sync = static_cast<int>(PINS_CAPTURE_SYNC);
    hw.pin_spi_sclk = static_cast<int>(PINS_SPI_SCLK);
    hw.pin_spi_mosi = static_cast<int>(PINS_SPI_MOSI);
    hw.pin_spi_miso = static_cast<int>(PINS_SPI_MISO);
    hw.pin_adc_cs = static_cast<int>(PINS_ADC_CS);
    hw.pin_dds_fsync = static_cast<int>(PINS_DDS_FSYNC);
    hw.pin_i2c_sda = static_cast<int>(PINS_I2C_SDA);
    hw.pin_i2c_scl = static_cast<int>(PINS_I2C_SCL);
    hw.si5351_addr = kSi5351Addr;
    hw.adc_ch_i = static_cast<uint8_t>(RECEIVER_ADC_CHANNEL_I);
    hw.adc_ch_q = static_cast<uint8_t>(RECEIVER_ADC_CHANNEL_Q);
    hw.adc_range_code = 1;   // +-2.5 x Vref (RECEIVER_ADC_FULL_SCALE_V)
    hw.tick_hz = TIMING_TICK_HZ;
    hw.raw_rate_hz = ACQUISITION_RAW_RATE_HZ;
    hw.adc_full_scale_v = RECEIVER_ADC_FULL_SCALE_V;
    hw.adc_bits = static_cast<int>(RECEIVER_ADC_BITS);
    hw.decimation = static_cast<size_t>(ACQUISITION_DECIMATION);
    hw.f_if_hz = RF_IF_FREQUENCY_HZ;
    hw.tx_freq_hz = TX_FREQUENCY_HZ;
    hw.lo_freq_hz = LO_FREQUENCY_HZ;
    hw.dds_mclk_hz = DDS_MCLK_HZ;
    hw.lo_xtal_hz = LO_CRYSTAL_HZ;
    hw.repetition_s = ACQUISITION_REPETITION_TIME_S;
    hw.gate_timeout_ms = 1000.0;
    return hw;
}

// A default water-FID experiment straight from the config: n_avg scans, CYCLOPS phase cycle.
bool make_program(pulse::Program& prog) {
    const std::vector<pulse::Scan> scans =
        pulse::fid(TX_T90_S, ACQUISITION_START_DELAY_S, ACQUISITION_DURATION_S,
                   static_cast<int>(ACQUISITION_AVERAGES), pulse::Cycle::Cyclops);
    pulse::Timing tm{TIMING_TICK_HZ, TX_FREQUENCY_HZ, TIMING_PRE_BLANK_S, RECEIVER_DEAD_TIME_S,
                     ACQUISITION_REPETITION_TIME_S};
    std::vector<pulse::Diagnostic> diag;
    if (!pulse::compile(scans, tm, prog, diag)) {
        for (const auto& d : diag) ESP_LOGE(TAG, "compile: [%u] %s", (unsigned)d.index, d.message.c_str());
        return false;
    }
    pulse::Limits lim{};
    lim.tick_hz = TIMING_TICK_HZ;
    lim.tx_max_pulse_s = LIMITS_TX_MAX_PULSE_S;
    lim.tx_max_duty = LIMITS_TX_MAX_DUTY;
    lim.dead_time_s = RECEIVER_DEAD_TIME_S;
    lim.pre_blank_s = TIMING_PRE_BLANK_S;
    lim.tx_max_freq_hz = DDS_MAX_OUTPUT_FREQUENCY_HZ;
    lim.tx_min_freq_hz = 0;
    lim.backend_has_sync_input = false;
    const auto v = pulse::validate(prog, lim);
    for (const auto& d : v) ESP_LOGE(TAG, "validate: [%u] %s", (unsigned)d.index, d.message.c_str());
    return v.empty();
}

void report(const fw::RunReport& r) {
    printf("\n=== run report ===\n");
    printf("scans: %u planned, %u complete\n", (unsigned)r.scans_planned, (unsigned)r.scans_complete);
    for (const auto& s : r.scans)
        printf("  scan %u: %u/%u frames, %u ovf, %u edges%s%s\n", (unsigned)s.scan, (unsigned)s.frames_taken,
               (unsigned)s.frames_expected, (unsigned)s.adc_overflows, (unsigned)s.capture_edges,
               s.capture_overflowed ? " CAP-OVF" : "", s.complete ? "" : " INCOMPLETE");
    if (r.averaged) {
        printf("averaged: fs=%.1f Hz, aligned=%s\n", r.out_fs_hz, r.aligned ? "yes" : "NO");
        printf("peak: f=%.2f Hz, |S|=%.4g, SNR=%.1f\n", r.peak.freq_hz, r.peak.amplitude, r.peak.snr);
    } else {
        printf("averaged: none (no complete records)\n");
    }
    printf("NOTE: software integration only. Not bench-validated; no measured FID/echo.\n");
}

}  // namespace

extern "C" void app_main() {
    ESP_LOGI(TAG, "nmr firmware: %s %s, config %s", INSTRUMENT_NAME, INSTRUMENT_REVISION, CONFIG_SHA256);

    const fw::Hardware hw = make_hardware();
    const int max_scans = static_cast<int>(ACQUISITION_AVERAGES);
    // Preallocated per-scan capacity: full-duration record (pre-decimation complex samples) x 2 conversions + margin.
    const size_t samples = static_cast<size_t>(std::llround(ACQUISITION_DURATION_S * ACQUISITION_RAW_RATE_HZ));
    const size_t max_frames = (samples + 256) * 2;

    static fw::Controller ctrl;
    if (ctrl.init(hw, max_scans, max_frames) != ESP_OK) {
        ESP_LOGE(TAG, "init failed at %s: %s", ctrl.last_where(), esp_err_to_name(ctrl.last_error()));
        return;
    }

    pulse::Program prog;
    if (!make_program(prog)) { ESP_LOGE(TAG, "program build/validate failed"); return; }

    if (ctrl.configure(prog) != ESP_OK) {
        ESP_LOGE(TAG, "configure failed at %s: %s", ctrl.last_where(), esp_err_to_name(ctrl.last_error()));
        return;
    }
    if (ctrl.arm() != ESP_OK) {
        ESP_LOGE(TAG, "arm failed at %s: %s (Si5351 present? LO clock up?)", ctrl.last_where(),
                 esp_err_to_name(ctrl.last_error()));
        return;
    }

    fw::RunReport r;
    if (ctrl.run(r) != ESP_OK) {
        ESP_LOGE(TAG, "run failed at %s: %s", ctrl.last_where(), esp_err_to_name(ctrl.last_error()));
        return;
    }
    report(r);

    ESP_LOGI(TAG, "state: %s", fw::state_name(ctrl.state()));
    while (true) vTaskDelay(pdMS_TO_TICKS(1000));
}

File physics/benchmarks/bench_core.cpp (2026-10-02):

// Benchmarks of the representative workloads (docs/physics.md#performance). Prints median of repeated runs.
#include <algorithm>
#include <chrono>
#include <cstdio>
#include <functional>
#include <vector>

#include "instrument_config.hpp"
#include "nmr/dsp.hpp"
#include "nmr/pipeline.hpp"
#include "nmr/sim.hpp"
#include "pulse/compiler.hpp"

using namespace nmr;
using namespace nmr::cfg;

static double time_ms(const std::function<void()>& f, int reps) {
    std::vector<double> t;
    for (int i = 0; i < reps; ++i) {
        const auto a = std::chrono::steady_clock::now();
        f();
        t.push_back(std::chrono::duration<double, std::milli>(std::chrono::steady_clock::now() - a).count());
    }
    std::sort(t.begin(), t.end());
    return t[t.size() / 2];
}

int main() {
    std::vector<Voxel> vox;
    const double tv = time_ms([&] { vox = voxelize(design_probe(), design_sample(), 0.0025); }, 3);
    std::printf("voxelize 2.5 mm grid: %zu voxels, %.1f ms\n", vox.size(), tv);

    pulse::Timing tm{TIMING_TICK_HZ, TX_FREQUENCY_HZ, TIMING_PRE_BLANK_S, RECEIVER_DEAD_TIME_S, ACQUISITION_REPETITION_TIME_S};
    pulse::Program prog;
    std::vector<pulse::Diagnostic> d;
    const double tc = time_ms([&] {
        pulse::compile(pulse::hahn_echo(TX_T90_S, TX_T180_S, 0.02, 0.02, static_cast<int>(ACQUISITION_AVERAGES), pulse::Cycle::Cyclops), tm, prog, d);
    }, 50);
    std::printf("compile Hahn echo x%d: %zu instructions, %.3f ms\n", static_cast<int>(ACQUISITION_AVERAGES), prog.code.size(), tc);
    const double tcp = time_ms([&] { pulse::compile(pulse::cpmg(TX_T90_S, TX_T180_S, 0.01, 64, 0.005, 4, pulse::Cycle::Cyclops), tm, prog, d); }, 20);
    std::printf("compile CPMG 64 echoes x4: %zu instructions, %.3f ms\n", prog.code.size(), tcp);

    pulse::compile(pulse::fid(TX_T90_S, ACQUISITION_START_DELAY_S, ACQUISITION_DURATION_S, 1, pulse::Cycle::None), tm, prog, d);
    InstrumentModel m = design_model();
    SimResult r;
    for (int k : {1, 8}) {
        m.interp = k;
        const double ts = time_ms([&] { r = simulate(prog, vox, m); }, 3);
        std::printf("simulate one FID scan (%zu voxels, %.2f s, %zu ADC samples/ch), interp %d: %.1f ms\n", vox.size(),
                    ACQUISITION_DURATION_S, r.records[0].i.size(), k, ts);
    }
    std::vector<RecordView> v(1);
    v[0] = {0, 0, r.records[0].t_first, r.records[0].t_excitation, 0, 0, r.records[0].f_tx - m.lo_hz,
            r.records[0].i.data(), r.records[0].q.data(), r.records[0].i.size()};
    PipelineConfig pc;
    pc.adc_rate = m.adc_rate; pc.adc_full_scale = m.adc_full_scale; pc.decimation = 4;
    Processed p;
    const double tp = time_ms([&] { p = process(v, pc); }, 10);
    std::printf("pipeline one record (%zu -> %zu samples): %.2f ms\n", v[0].n, p.average.size(), tp);
    for (size_t n : {4096u, 65536u}) {
        std::vector<dsp::cplx> x(n, 1.0);
        dsp::FftPlan plan(n);
        const double tf = time_ms([&] { plan.execute(x.data()); }, 20);
        std::printf("FFT %zu points: %.3f ms\n", n, tf);
    }
    std::vector<dsp::cplx> x(4096, 1.0), y(4096);
    const double td = time_ms([&] { dsp::dft_reference(x.data(), y.data(), 4096); }, 3);
    std::printf("naive DFT 4096 points (legacy approach): %.1f ms\n", td);
    return 0;
}

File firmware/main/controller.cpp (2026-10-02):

#include "controller.hpp"

#include <algorithm>
#include <cmath>

#include "driver/gpio.h"
#include "esp_heap_caps.h"
#include "esp_log.h"
#include "freertos/FreeRTOS.h"
#include "freertos/task.h"

#include "rf.hpp"

namespace fw {

static const char* TAG = "ctrl";

const char* state_name(State s) {
    switch (s) {
        case State::Idle: return "Idle";
        case State::Configured: return "Configured";
        case State::Armed: return "Armed";
        case State::Running: return "Running";
        case State::Complete: return "Complete";
        case State::Aborting: return "Aborting";
        case State::Fault: return "Fault";
    }
    return "?";
}

bool transition_allowed(State from, State to) {
    if (to == State::Fault) return true;              // any failure may fault
    if (to == State::Aborting) return true;           // abort from anywhere
    switch (from) {
        case State::Idle:       return to == State::Configured;
        case State::Configured: return to == State::Armed || to == State::Configured;  // reconfigure
        case State::Armed:      return to == State::Running || to == State::Configured; // re-arm via reconfigure
        case State::Running:    return to == State::Complete;
        case State::Complete:   return to == State::Configured || to == State::Armed;   // next experiment / re-run
        case State::Aborting:   return to == State::Idle;
        case State::Fault:      return false;          // latched: only a reset (new init) leaves Fault
    }
    return false;
}

bool Controller::set_state(State to) {
    if (!transition_allowed(state_, to)) {
        ESP_LOGE(TAG, "illegal transition %s -> %s", state_name(state_), state_name(to));
        fault("set_state", ESP_ERR_INVALID_STATE);
        return false;
    }
    state_ = to;
    return true;
}

void Controller::safe_outputs() {
    // TX off (0), receiver blanked (0), phase register 0. All-zero is the safe level for every gate pin.
    const int pins[3] = {hw_.pin_tx_gate, hw_.pin_rx_open, hw_.pin_phase_sel};
    for (int p : pins) {
        if (p < 0) continue;
        gpio_config_t gc = {};
        gc.pin_bit_mask = 1ull << p;
        gc.mode = GPIO_MODE_OUTPUT;
        gpio_config(&gc);
        gpio_set_level(static_cast<gpio_num_t>(p), 0);
    }
}

esp_err_t Controller::fault(const char* where, esp_err_t e) {
    where_ = where;
    last_err_ = e;
    adc_.stop();
    safe_outputs();
    state_ = State::Fault;
    ESP_LOGE(TAG, "FAULT at %s: %s", where, esp_err_to_name(e));
    return e;
}

esp_err_t Controller::init(const Hardware& hw, int max_scans, size_t max_frames_per_scan) {
    hw_ = hw;
    max_scans_ = max_scans;
    cap_samples_ = max_frames_per_scan / 2;   // two conversions (I and Q) per complex sample

    // Safe before any peripheral is configured, in case we faulted out of a previous run.
    safe_outputs();

    // Preallocated record pool: prefer PSRAM, fall back to internal RAM (will fail loudly if too large).
    const size_t n = static_cast<size_t>(max_scans_) * cap_samples_;
    const uint32_t caps = MALLOC_CAP_SPIRAM | MALLOC_CAP_8BIT;
    pool_i_ = static_cast<int16_t*>(heap_caps_malloc(n * sizeof(int16_t), caps));
    pool_q_ = static_cast<int16_t*>(heap_caps_malloc(n * sizeof(int16_t), caps));
    if (!pool_i_ || !pool_q_) return fault("init/pool", ESP_ERR_NO_MEM);
    records_.reserve(max_scans_);

    EngineConfig ec{};
    ec.pin_tx_gate = hw_.pin_tx_gate;
    ec.pin_rx_open = hw_.pin_rx_open;
    ec.pin_phase_sel = hw_.pin_phase_sel;
    ec.pin_dds_sign = hw_.pin_dds_sign;
    ec.pin_lo_i = hw_.pin_lo_i;
    ec.pin_ws = hw_.pin_adc_cs;             // the ADS8688 /CS is the I2S WS: its first edge marks frame 0
    ec.pin_sync = hw_.pin_capture_sync;
    ec.tick_hz = static_cast<uint32_t>(llround(hw_.tick_hz));
    esp_err_t e = engine_.init(ec);
    if (e != ESP_OK) return fault("init/engine", e);

    AdcConfig ac{};
    ac.pins = {hw_.pin_spi_sclk, hw_.pin_spi_mosi, hw_.pin_spi_miso, hw_.pin_adc_cs};
    ac.frame_rate = static_cast<uint32_t>(llround(hw_.raw_rate_hz * 2.0));   // I and Q conversions per second
    ac.ch_i = hw_.adc_ch_i;
    ac.ch_q = hw_.adc_ch_q;
    ac.range_code = hw_.adc_range_code;
    ac.capacity_frames = max_frames_per_scan;
    if ((e = adc_.init(ac)) != ESP_OK) return fault("init/adc", e);

    components_up_ = true;
    state_ = State::Idle;
    ESP_LOGI(TAG, "init ok: pool %u samples/scan x %d scans", (unsigned)cap_samples_, max_scans_);
    return ESP_OK;
}

esp_err_t Controller::configure(const pulse::Program& prog) {
    if (state_ == State::Fault) return ESP_ERR_INVALID_STATE;
    if (!components_up_) return fault("configure", ESP_ERR_INVALID_STATE);

    pulse::Diagnostic d{};
    events_.clear();
    if (!pulse::expand(prog, events_, d)) return fault("configure/expand", ESP_ERR_INVALID_ARG);
    n_scans_ = pulse::count_scans(events_);
    if (n_scans_ == 0) return fault("configure/no-scans", ESP_ERR_INVALID_ARG);
    if (static_cast<int>(n_scans_) > max_scans_) return fault("configure/too-many-scans", ESP_ERR_INVALID_SIZE);

    // Pre-arm check: every scan must plan, and its acquisition window must fit the preallocated record.
    for (size_t k = 0; k < n_scans_; ++k) {
        pulse::ScanPlan plan;
        pulse::Diagnostic pd;
        if (!pulse::plan_scan(events_, k, pulse::BackendCaps{}, plan, pd))
            return fault("configure/plan", ESP_ERR_INVALID_ARG);
        if (plan.nwin == 0) return fault("configure/no-window", ESP_ERR_INVALID_ARG);
        const double win_s = static_cast<double>(plan.win[0].end - plan.win[0].start) / hw_.tick_hz;
        const size_t samples = static_cast<size_t>(llround(win_s * hw_.raw_rate_hz));
        if (samples > cap_samples_) return fault("configure/window-too-long", ESP_ERR_INVALID_SIZE);
    }

    if (!set_state(State::Configured)) return last_err_;
    ESP_LOGI(TAG, "configured: %u scans", (unsigned)n_scans_);
    return ESP_OK;
}
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

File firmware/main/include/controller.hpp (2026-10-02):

// Instrument control plane: the one place that sequences RF setup, gate waveforms, acquisition and DSP for an
// experiment. It owns the state machine and the shared buses; the components (engine/adc/rf) and the shared pulse/DSP
// core do the work. Everything outside a running scan is control plane (SPI/I2C free to program the DDS and clock);
// inside a scan the gate engine and the I2S ADC own the pins and the CPU only waits and copies finished buffers.
//
// Safety is structural: the gate pins idle at their safe levels (TX off, receiver blanked), every failure drives them
// back there and latches Fault, and buffers are preallocated with explicit capacities so a scan never allocates and an
// over-long or lossy record is reported, never silently truncated.
#pragma once

#include <cstddef>
#include <cstdint>
#include <vector>

#include "esp_err.h"

#include "adc_stream.hpp"
#include "engine.hpp"
#include "nmr/dsp.hpp"
#include "nmr/pipeline.hpp"
#include "pulse/backend.hpp"
#include "pulse/program.hpp"

namespace fw {

// Pin and channel map + derived rates, filled from generated/instrument_config.hpp in main.cpp so this unit does not
// depend on the generated header directly (and can be built against a test map).
struct Hardware {
    // gate engine
    int pin_tx_gate, pin_rx_open, pin_phase_sel;
    int pin_dds_sign, pin_lo_i;   // ECO-1 reference captures (-1 if unwired)
    int pin_capture_sync;         // firmware-internal common timebase reset
    // shared SPI bus (ADS8688 during a scan, AD9834 between scans)
    int pin_spi_sclk, pin_spi_mosi, pin_spi_miso, pin_adc_cs, pin_dds_fsync;
    // Si5351 I2C
    int pin_i2c_sda, pin_i2c_scl;
    uint8_t si5351_addr;
    // ADS8688 channels / range
    uint8_t adc_ch_i, adc_ch_q, adc_range_code;

    double tick_hz;               // pulse-program tick (must match engine)
    double raw_rate_hz;           // complex samples/s per channel before decimation
    double adc_full_scale_v;
    int adc_bits;
    size_t decimation;
    double f_if_hz;               // f_tx - f_lo
    double tx_freq_hz, lo_freq_hz, dds_mclk_hz, lo_xtal_hz;
    double repetition_s;          // scan start to scan start (>= T1)
    double gate_timeout_ms;       // RMT wait timeout per scan
};

enum class State : uint8_t { Idle, Configured, Armed, Running, Complete, Aborting, Fault };
const char* state_name(State s);

// Allowed state transitions. Pure and side-effect free so the table can be unit-tested without hardware.
bool transition_allowed(State from, State to);

// Per-scan acquisition outcome. A record is complete only if the expected frame count arrived with no DMA overflow and
// no capture-edge overflow; otherwise the record is flagged and never fed to the average as if it were whole.
struct ScanReport {
    uint32_t scan = 0;
    size_t frames_expected = 0;
    size_t frames_taken = 0;
    uint32_t adc_overflows = 0;
    size_t capture_edges = 0;
    bool capture_overflowed = false;
    double actual_lo_hz = 0;      // Si5351 CLK1/4 actually synthesised (first scan)
    bool complete = false;
};

struct RunReport {
    size_t scans_planned = 0;
    size_t scans_complete = 0;
    std::vector<ScanReport> scans;
    bool averaged = false;
    bool aligned = true;          // pipeline: every scan had the same sample timing vs excitation
    nmr::dsp::Peak peak{};        // peak of the averaged, windowed spectrum
    double out_fs_hz = 0;
};

class Controller {
public:
    // Allocate the preallocated record pool (PSRAM) and bring the gate pins to safe levels. On any failure the pins are
    // driven safe and the state latches Fault.
    esp_err_t init(const Hardware& hw, int max_scans, size_t max_frames_per_scan);

    // Decode/validate a program against the hardware limits and confirm it fits the preallocated capacities.
    esp_err_t configure(const pulse::Program& prog);

    // Control-plane RF: clock (Si5351) then DDS. Bus is owned here, between scans only.
    esp_err_t arm();

    // Run every scan: plan -> load gates -> program per-scan DDS phase -> acquire -> copy -> average -> spectrum/peak.
    // Stops and reports on the first unrecoverable error; incomplete records are flagged, not hidden.
    esp_err_t run(RunReport& out);

    // Force safe outputs immediately (TX off, receiver blanked, ADC stopped) and return to Idle. Safe to call anytime.
    void abort();

    State state() const { return state_; }
    esp_err_t last_error() const { return last_err_; }
    const char* last_where() const { return where_; }

private:
    bool set_state(State to);          // guarded; false (and Fault) on an illegal transition
    void safe_outputs();               // drive the three gate pins to their safe levels via GPIO
    esp_err_t fault(const char* where, esp_err_t e);   // safe outputs + latch Fault
    esp_err_t run_scan(size_t k, ScanReport& sr);

    Hardware hw_{};
    GateEngine engine_;
    AdcStream adc_;

    std::vector<pulse::Event> events_;
    size_t n_scans_ = 0;
    bool components_up_ = false;

    // preallocated per-scan de-interleaved I/Q (PSRAM), [max_scans][max_frames/2]
    int max_scans_ = 0;
    size_t cap_samples_ = 0;        // complex samples per scan a record may hold
    int16_t* pool_i_ = nullptr;
    int16_t* pool_q_ = nullptr;
    std::vector<nmr::RecordView> records_;

    double actual_lo_hz_ = 0;       // Si5351 CLK1/4 actually synthesised, set in arm()

    State state_ = State::Idle;
    esp_err_t last_err_ = ESP_OK;
    const char* where_ = "";
};

}  // namespace fw

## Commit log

2026-10-02 Project 3 (Yi-Tsai): housing, probe and data models, design stage
    docs/students/yi-tsai/housing/: printed housing, probe and B0 pair,
    the whole bench with its cross-checks, a physics simulator and a
    3D-printed data model, laser / water-jet versions of every part, and
    a README as the landing page for the class-wall card. Nothing printed,
    cut or measured yet.
    [base-shell.stl, boards.scad, bottom-plate.dxf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]
2026-10-02 Project 3 (Yi-Tsai): NMR bench simulator in housing/sim
    A live 3D view of the setup (probe, B0 Helmholtz pair, housing, cables) built from
    the .scad models, with a pulse experiment that solves the Bloch equations for 3000
    voxels in the real B0 and B1 fields and runs the receiver chain (tank, IF, noise).
    It shows a 451 us 90-degree pulse at the coil centre (not 417), 8 uV at the tank
    for the 50 mL tube (a fifth of the design's 40 uV) and a T2* of about 72 ms.
    [exp-housing.scad, exp-probe.scad]
2026-10-02 NMR bench simulator
    [exp-housing.scad, exp-probe.scad]
2026-10-02 Project 3 (Yi-Tsai): landing page as a step-by-step walkthrough
    README.md rewritten in the style of an exercise page: boards, two
    cover heights, cut-outs, labels and the B0 scale, fasteners, coupon,
    probe, B0 pair, simulator and data model, flat parts, what's next.
    Renders for each step in img/.
2026-10-02 Show the sample: see-through probe, 400 water voxels at their real places, net M at the water's centre
2026-10-02 Project 3 (Yi-Tsai): simulator shows the sample - water voxels in place inside a see-through probe
2026-10-02 Make nmr-instrument the canonical Project 3 home
    - index.html: the Project 3 site (housing, probe, simulated data,
    fabrication, hardware & firmware, the three interfaces)
    - simulator/: NMR Bench Setup moved here (git mv); labelled as a
    simulation that cannot control the instrument, with a link to the real
    sequence (runOneScan() in class-board-2026 Sequencer.cpp @ eef00d2)
    - mechanical/: the OpenSCAD project, brought in from class-board-2026
    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
    [boards.scad, cut-common.scad, cut-housing__cover.cut.dxf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]
2026-10-02 Simulator: exact fields from Mathematica, checked against SpinDynamica
    build/nmr_exact.wls computes the field at every voxel of the water by Biot-Savart (B0 pair
    with its real 28 x 27 mm winding cross-section, each of the class coil's 400 turns) and runs
    the pulse on every voxel with SpinDynamica 3.7.1. The maps (m/fieldmap-tube.json,
    m/fieldmap-bottle.json) now drive physics.js; the old 4th-order model stays as the
    "Approximate" switch and the fallback. With identical voxels physics.js matches SpinDynamica
    (emf 0.902 uV, line 89 560 Hz, FWHM 6 Hz, T2* 80 vs 80.5 ms).
    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
2026-10-02 v2 M0+M1: audit, legacy/ moved, canonical instrument.yaml with schema, generator and tests
    [base-shell.stl, boards.scad, bottom-plate.dxf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]
2026-10-02 Force LF line endings so generated files compare byte-exactly on every OS
    [base-shell.stl, bottom-plate.dxf, coupon.stl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]
2026-10-02 v2 M2+M3: C++ physics/DSP core, pulse IR + compiler + validator, digital-twin simulator, C ABI, Python binding, tests and benchmarks
    Native: test_bloch 26, test_field 29, test_dsp 15, test_pulse 31, test_sim 14 checks pass.
    Golden: every voxel of both legacy Biot-Savart maps reproduced (df 0.55 mHz, b1 5e-6 rel, phi 5e-5 rad).
    [bench_core.cpp, capi.cpp]
2026-10-02 v2: WASM build of the same core, JS loader with ABI layout check, native-vs-WASM parity test (bit-identical ADC codes)
2026-10-02 v2 M4 WIP (as recovered): planner backend, 125 kS/s config, ESP-IDF firmware components
    Snapshot of the uncommitted work found on branch v2 after the account
    switch, committed verbatim before any new edits so there is a clean
    restore point. No content changed during recovery.
    Contents:
    - pulse backend planner (pulse/{include,src}/backend) + physics/tests/test_backend.cpp
    - config to raw 125 kS/s / decimation 5, ECO-1 capture pins, N16R8 (design/instrument.yaml,
    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
2026-10-02 Add recovery handoff package (2026-10-03)
    Handoff docs reconstructed from an older main-snapshot ZIP plus the
    execution transcript: current state, recovery plan, next actions, open
    issues, decision log, test evidence and supporting artifacts. Preserved
    in the repo as recovery evidence. Statuses are TRANSCRIPT_REPORTED /
    historical, not bench-validated.
2026-10-02 v2: rebuild WASM core from current config, re-establish native/WASM parity
    The committed nmrcore.wasm predated the 125 kS/s / decimation-5 config
    change, so its embedded config sha (b759cbb0...) no longer matched the
    native build (5469d421...) and tests/test_wasm_parity.py failed.
    Rebuilt from the current shared sources (393 KiB); parity now passes
    (bit-identical ADC codes, config sha matches). Closes SIM-PARITY-001.
    Evidence (LIVE_REVALIDATED, 2026-10-03, this machine):
    py tools/gen_config.py --check -> up to date
    cmake --build build; ctest -> 6/6 suites pass
    py -m pytest -q tests -> 16 passed
2026-10-02 v2 M4: firmware main/control integration; firmware now builds (FW-RESUME-01, -03)
    Completes the interrupted continuation point: the ESP-IDF firmware had
    engine/adc/rf components but an empty main/. Adds the control plane that
    sequences an experiment end to end, wiring the existing components and the
    shared pulse/DSP core (no duplicate drivers).
    firmware/main/:
    - controller.{hpp,cpp}: state machine Idle->Configured->Armed->Running->Complete
    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
    [default_16MB.csv]
2026-10-02 Ignore PlatformIO-generated firmware/sdkconfig.esp32s3
2026-10-02 Checkpoint 01: Case-1 recovery, SIM-PARITY-001 closed, firmware builds (live-verified)
2026-10-02 v2: FW-IQ-001 I/Q aperture-skew correction in the shared pipeline + simulator
    The ADS8688 auto-sequence converts the two channels one conversion period apart
    (~0.5 raw samples; ~7.8 deg at the 5.4 kHz IF), so I is sampled slightly after Q.
    Correct it once in the shared DSP so firmware, host tools and the browser agree.
    - dsp::frac_delay: centred windowed-sinc fractional-delay FIR (out[k] ~= x(k-delay)),
    unity DC gain, delay 0 is an exact copy; edges zero-padded and bounded.
    - pipeline: opt-in PipelineConfig.iq_skew_samples (default 0 = off, so the C ABI
    struct nmr_pipeline and WASM parity are untouched); when set, the I channel is
    fractionally delayed onto Q's grid before mixing.
    - si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
    [controller.cpp, pipeline.cpp, pipeline.hpp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]
2026-10-02 v2: browser digital-twin simulator UI driven by the WASM core
    The v2 site had the WASM core (nmrcore.wasm + loader) but no page using it;
    the old site/simulator were moved under legacy/. Add the real front end.
    - simulator/index.html: self-contained app (no external deps). FID / Hahn echo /
    inversion recovery / CPMG, with sample+field controls (B0 current, T1, T2, f_tx,
    grid), receiver/DSP controls (noise, LO coherence, beat correction, apodization,
    seed), KPIs (Larmor, line offset, SNR, FWHM, clipping) and canvas plots of the
    pulse sequence, the averaged baseband FID/echo (I, Q, |M|) and the spectrum with
    peak/SNR. Every number is computed by the WASM core, not re-done in JS.
    - i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
2026-10-02 v2: end-to-end device site — signal-path console + integrated landing
    Rework the browser simulator so it reflects the firmware signal path, and
    integrate it with (not replace) the original build walkthrough.
    Signal-path console (simulator/index.html): five stages, each a real firmware
    stage driven by the shared WASM core —
    1. Pulse program (IR, disassembled) — what the firmware loads/validates
    2. Gate engine — TX_EN / RX_BLANK / PSELECT waveforms + markers + ACQ window,
    decoded from the compiled program (the edges the RMT peripheral emits)
    3. ADC (ADS8688/I2S) — raw 16-bit I/Q codes, with the I/Q aperture skew and its
    correction toggleable (FW-IQ-001)
    4. DSP pipe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
    [capi.cpp]
2026-10-02 v2: enhance probe OpenSCAD — lead-in chamfers, assembly self-checks, BOM
    Additive detail to legacy/mechanical/probe.scad (printed parts only; the laser-cut
    cut-probe.scad and its DXF/SVG are untouched; probe geometry unchanged):
    - parametric 45-degree lead-in chamfers at both former bore mouths and the sleeve's
    open end, so the sleeve / 50 mL tube find the bore without catching a print lip
    - file-scope assert()s that fail loudly: sleeve wall >= 0.8 mm, tube tip within the
    former, winding build <= cheek rim, B0 pair within the H-bridge limits
    - a consolidated BOM echo (printed / laser / wire / no-steel hardware) and a CHECK
    summary line
    - regenerated probe-former/sleeve/cradle STLs fr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
    [probe-cradle.stl, probe-former.stl, probe-sleeve.stl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]
2026-10-02 tools/nmr-render: local CPU render-to-PNG oracle for the 3-D scene
    A small native renderer so visual choices (camera, framing, sample-holder
    visibility, B0/B1 readability, transparency, exploded view) are inspected from a
    PNG, not guessed from source.
    - transcode.mjs: re-containers the canonical packed meshes legacy/simulator/m/*.txt
    (the same the Three.js site loads; from the OpenSCAD via build/pack.py) into one
    assets/scene.bin. Geometry is NOT redefined here.
    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
2026-10-02 Phase F: apply renderer-validated presentation to the WebGL simulator
    Camera/visibility choices verified in tools/nmr-render, now ported to the public
    Three.js bench (geometry unchanged):
    - narrow FOV (35 -> 13-18 per preset): near/far Helmholtz rings read at nearly the
    same size; no more wide-angle "huge near ring" distortion
    - default view recentred on the probe/sample ([0,0,AXIS]); presets carry a per-view
    fov + which part groups are shown + whether the field is on
    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
2026-10-03 docs: design-closure — Phase 1 audit + Phase 2 physics closure (quantified)
    Engineering-closure working doc. Investigation-before-redesign, with real numbers
    from the shared field solver over the voxelised 50 mL tube (I=1.5 A):
    - B0 over the sample: f_mean 89528 Hz, p2p 304 Hz (3400 ppm), receive-weighted
    RMS 35 Hz. Field flat to ±~30 mm along the coil axis, then drops hard
    (-116 Hz at -50 mm, -204 Hz at -60 mm).
    - Active-length vs linewidth (receive-weighted): 100 mm -> 23.9 Hz RMS, only 11%
    of signal within ±5 Hz; 60 mm -> 4.4 Hz RMS, 82% within ±5 Hz at 78% signal;
    40 mm -> 1.6 Hz at 55%. The 100 mm coil/50 mL sample is TOO LONG for the B0
    homogeneous volume; ~60 mm active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
2026-10-03 Phase 3: adopt the 60 mm RF active region (coupled physics + config + CAD)
    Quantified in docs/design-closure.md: the 100 mm coil/50 mL sample was too long for
    the B0-homogeneous volume (receive-weighted field RMS 24 Hz, 11% of signal within
    ±5 Hz). 60 mm keeps 78% of signal at 4.4 Hz RMS. Done end to end through the single
    source of truth, verified green:
    - design/instrument.yaml rf_coil -> 60 mm, 266 turns (2x133); B1/I 4.611195e-3 T/A
    (Biot-Savart solver), L~1.87 mH, R~4.46 ohm (estimates, to be measured). gen_config
    recomputed the chain (t90 -> 369 us, coil current 6.9 mA) and passed all checks.
    - Validation frozen at 100 mm: added legacy_probe() + ABI nmr_legacy_fields_at;
    test_f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
    [probe-cradle.stl, probe-former.stl, probe-sleeve.stl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]
2026-10-03 Phase 4: magnet structural closure + common baseplate
    The B0 pair's laser-cut rails + braces (cut-probe.scad) seat both ring stacks at the
    200 mm spacing but were never in the 3-D assembly, and nothing tied the magnet, probe
    and electronics to one reference. Added, as faithful solids from the same rail/ring
    numbers (x = coil axis, y = B0, z = up):
    - cut-probe.scad: b0_rail3d/b0_brace3d (two rails at x=±100 seating the rings, braces
    tying them) + baseplate() carrying both rails and the probe tripod -> one datum.
    Clearance echo confirms the baseplate spans both rails + the probe.
    - exp-probe.scad: new render comps (baseplate, magnet_frame); sim meshes packed.
    - legacy/simulator/index.htm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
    [cut-probe.scad, exp-probe.scad]
2026-10-03 Phase 5: electronics integration — bench feet + cable strain relief
    housing.scad was already a complete electronics enclosure with real board dimensions
    (180x115 KiCad frame, M3 holes [[4,19],[176,19],[4,111],[176,111]], cover standoffs,
    laser-cut bottom plate on nut-pocket bosses, SMA/OLED/terminal cut-outs, service
    access) and a defined position in instrument.scad (450 mm from the sample, for RF
    isolation). So the "floating PCB" concern did not apply. Added the two genuine gaps:
    - housing_feet(): four feet under the bottom plate (verified z -40.7 -> -45.7, 5 mm
    proud), for bench stability.
    - strain_relief(): a clamp bar outside the front/terminal wall with zip-tie slots, so
    a cable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
    [housing.scad]
2026-10-03 Phase 6: full instrument assembly + interference/serviceability pass (clean)
    The whole bench is one assembly now (baseplate -> magnet rails/braces cradling both
    rings -> probe on its tripod at the magnetic centre -> cables -> electronics). Added
    an "assembly" preset to tools/nmr-render and inspected the render.
    Interference/serviceability screen (AABB over the assembled scene + model self-checks
    + instrument.scad echoes) is clean:
    - probe radial envelope 17-23 mm inside the ring aperture (171 mm) -> no collision
    - rings clear the baseplate by 10 mm; tripod seated; cables stay above the plate
    - electronics 236 mm clear of the magnet; nearest steel 492 mm; rings clear the housing
    - serviceabi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
    [cut-probe.scad]
2026-10-03 Phase 7: regenerate fabrication files + BOM + assembly order (60 mm design)
    Closes the CAD/design side. Re-ran export_cut.py from the closed cut-*.scad:
    - cheek engraving 400T -> 266T; cradle_base saddle positions follow the 60 mm winding;
    all other laser/water-jet parts byte-identical. legacy/fabrication/CUT-LIST.md
    regenerated (wire 45 m, former ~95 mm, the frame + assembly-clearance checks).
    - docs/assembly.md: bill of materials summary + step-by-step assembly order (probe ->
    sample datum -> cradle -> magnet -> base/frame -> electronics -> cables), pointing to
    CUT-LIST.md for parts and design-closure.md for commissioning + acceptance criteria.
    Everything after this needs the phys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
    [cut-probe.scad, cut-probe__cheek.engrave.dxf, cut-probe__cheek_lead.engrave.dxf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]
